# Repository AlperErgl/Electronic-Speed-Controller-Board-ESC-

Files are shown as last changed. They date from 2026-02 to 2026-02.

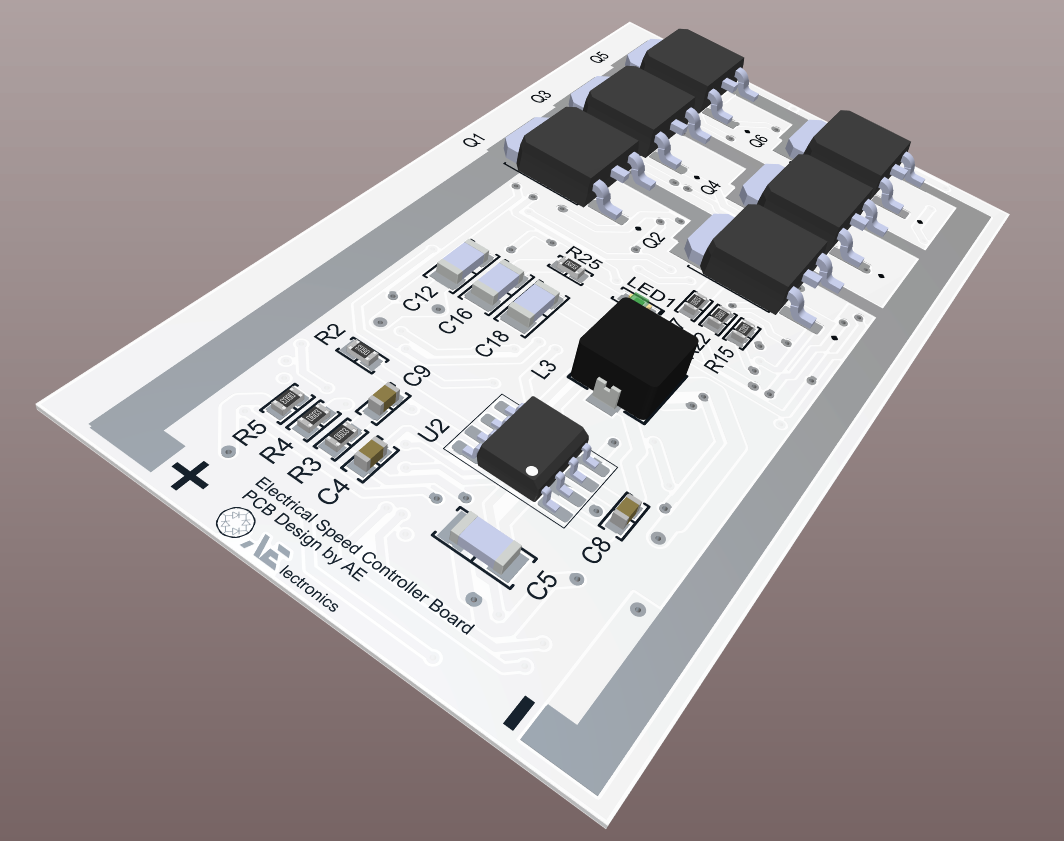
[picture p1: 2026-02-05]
ESC_Hardware/Documentation/Images/ESC Perspective View.png

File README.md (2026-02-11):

# Electronic-Speed-Controller-Board-ESC
Electronic Speed Controller (ESC) using PWM control, developed in C for embedded applications.

ESC Perspective View-Photoroom
 <p align="center">
 <i>Figure 1. Electronic Speed Controller Perspective View.</i>
</p>

## Project Overview

This project focuses on the design and implementation of a sensorless Brushless DC (BLDC) Electronic Speed Controller (ESC) developed as part of a graduation thesis. The system integrates both hardware and firmware, aiming to achieve reliable motor control using low-cost components and an open-source development approach.

The ESC is built around an ATmega328P microcontroller and operates using Back-EMF zero-crossing detection to determine rotor position without the use of Hall sensors. This sensorless approach reduces system complexity, cost, and mechanical dependency while maintaining efficient motor commutation.

The firmware is written in C/Arduino-based embedded C, directly configuring microcontroller registers for precise timing, PWM generation, and interrupt handling. The ESC accepts a standard RC PWM input signal (1000–2000 µs) and dynamically maps it to motor speed by adjusting PWM duty cycles.

On the hardware side, a custom PCB was designed, including MOSFET driver stages, power regulation, signal conditioning, and protection considerations. The project also includes EEPROM-based parameter storage, allowing the ESC to automatically learn and store throttle range values during configuration.

This project demonstrates practical experience in:

- Embedded systems programming

- Power electronics

- Motor control theory

- PCB design and hardware–software co-design

## Features

- Sensorless BLDC Motor Control
Uses Back-EMF zero-crossing detection for rotor position estimation without Hall sensors.

- Custom ESC Firmware
Firmware developed in embedded C with direct register-level control for timers, PWM, and interrupts.

- Standard RC PWM Input Support
Compatible with 1000–2000 µs PWM signals from RC receivers or flight controllers.

- Automatic Throttle Range Calibration
Throttle minimum and maximum values are detected on startup and stored in EEPROM.

- EEPROM-Based Parameter Storage
Persistent storage of configuration parameters across power cycles.

- Multi-Step Commutation Sequence
Six-step trapezoidal commutation with comparator-based zero-cross detection.

- Audible Status Feedback
Startup, configuration, and error states indicated via buzzer tones at different frequencies.

- Custom PCB Design
Includes schematic design, PCB layout, Gerber files, and Bill of Materials (BOM).

- Low-Cost and Open-Source Approach
Designed using widely available components and open development tools.

## Hardware Design

The hardware design of this Electronic Speed Controller (ESC) is based on a modular and clearly structured three-phase inverter topology, optimized for sensorless BLDC motor control. The system is powered by a Li-Po battery, which serves as the main DC energy source and is capable of supplying the high current required by the motor. To support the low-voltage control electronics, the battery voltage is stepped down using a high-efficiency switching regulator (MP2307DN-LF-Z), providing a stable 5 V supply rail for the microcontroller and auxiliary circuitry. The use of a switching regulator instead of a linear solution significantly improves efficiency and reduces thermal losses, which is critical for battery-powered systems.

<br>
<p align="center">
Başlıksız DiyagramDD drawio
</p>
<p align="center">
  <i>Figure 2. Overall hardware topology of the Electronic Speed Controller.</i>
</p>

<br>

At the core of the control system lies the ATmega328P microcontroller in a 32-pin LQFP package. The microcontroller is responsible for PWM signal generation, RC input signal processing, commutation timing, and Back-EMF zero-crossing detection. One of the key reasons for selecting the ATmega328P is its built-in analog comparator, which enables sensorless motor control without the need for external Hall sensors. This allows rotor position estimation by monitoring the floating motor phase voltage during each commutation step.

The motor drive stage consists of six IRLR7843 N-channel power MOSFETs arranged in a three-phase half-bridge configuration. These MOSFETs were selected due to their low RDS(on), logic-level gate drive compatibility, and high current handling capability, making them suitable for low-voltage, high-current BLDC applications. Each motor phase is driven by a complementary high-side and low-side MOSFET pair, allowing precise control of current flow through the motor windings.

Gate control for the MOSFETs is provided by three IR2101 high-side / low-side gate driver ICs, with each driver dedicated to one motor phase. The IR2101 enables reliable high-side N-channel MOSFET driving through internal level shifting and bootstrap circuitry. This architecture ensures fast switching transitions, proper gate voltage levels, and safe operation by minimizing the risk of shoot-through conditions.

The three motor phases are structured as AH/AL for Phase A, BH/BL for Phase B, and CH/CL for Phase C, where the high-side (H) MOSFET connects the phase to the positive supply rail and the low-side (L) MOSFET connects it to ground. During operation, the ESC follows a six-step trapezoidal commutation sequence. At any given time, one phase is actively driven high, one phase is driven low, and the remaining phase is left electrically floating. The floating phase voltage is used for Back-EMF sensing, allowing the microcontroller to detect zero-crossing events and determine the optimal timing for the next commutation step.

<br>
<p align="center">
ESC-Circuit
</p>
<p align="center">
  <i>Figure 3. ESC Circuit Diagram.</i>
</p>

The complete electrical implementation of this architecture can be seen in the provided schematic diagram, which illustrates the power stage, gate driver connections, microcontroller interfacing, and Back-EMF sensing paths. The schematic highlights the separation between high-power and low-power domains, ensuring both electrical safety and signal integrity. Special attention has been given to grounding, decoupling, and signal routing to improve noise immunity and overall system reliability.

<br>
<p align="center">
ESC Bottom 2D
</p>
<p align="center">
  <i>Figure 4. ESC Bottom 2D View.</i>
</p>

Overall, the hardware design achieves a balance between performance, simplicity, and educational clarity. It demonstrates a fully functional sensorless BLDC ESC architecture using widely available components, making it suitable for academic projects, prototyping, and further development.

<br>
<p align="center">
ESC Bottom View
</p>
<p align="center">
  <i>Figure 5. ESC 3D View.</i>
</p>

## Firmware / Software Design

The ESC firmware is implemented in C/C++ using the Arduino framework and is specifically designed for real-time, sensorless BLDC motor control. The software architecture follows a modular design approach, where motor control logic, hardware abstraction, persistent configuration storage, and user feedback mechanisms are separated into dedicated source and header files. This structure improves maintainability, enhances code readability, and allows individual subsystems to be modified or extended independently without affecting the overall system behavior.

### PWM Input Measurement and Processing

The main firmware file (ESC_V3_Code.ino) handles system initialization, PWM input measurement, motor state control, and commutation sequencing. During startup, all GPIOs, timers, and internal peripherals are configured. The incoming PWM signal from the RC receiver is measured and mapped to a valid motor speed range while enforcing predefined safety limits.

```c
if (PWM_INPUT > PWM_IN_MAX) PWM_INPUT = PWM_IN_MAX;
if (PWM_INPUT < PWM_IN_MIN) PWM_INPUT = PWM_IN_MIN;

```
This ensures that invalid or noisy input signals cannot command unsafe motor behavior.
<br>
<br>
### Sensorless Commutation and Back-EMF Detection

Motor commutation is implemented using a six-step trapezoidal algorithm. At each step, two phases are actively driven while the third phase is left floating. The floating phase voltage is monitored using the ATmega328P’s internal analog comparator to detect Back-EMF zero-crossing events, which are used to determine the correct timing for the next commutation step.

This method enables fully sensorless operation without external position sensors, reducing system complexity and hardware cost.
<br>
<br>
### PWM Generation and Motor Speed Control

Motor speed is controlled by adjusting the PWM duty cycle applied to the active MOSFETs. Hardware timers are used to generate stable PWM signals, allowing precise control over the effective motor voltage.

```c
#define PWM_max_value 255
#define PWM_min_value 35
```
These limits prevent operation in regions where torque is insufficient or switching losses become excessive.
<br>
<br>
### Non-Volatile Configuration Storage (EEPROM)

Calibration parameters such as minimum and maximum PWM input values are stored in EEPROM to persist across power cycles. A generic EEPROM abstraction layer allows arbitrary data types to be stored and retrieved safely.

```c
EEPROM_writeAnything(PWM_IN_MIN_ADRESS, PWM_IN_MIN);
EEPROM_readAnything(PWM_IN_MAX_ADRESS, PWM_IN_MAX);
```
This feature eliminates the need for repeated calibration and improves user experience.
<br>
<br>
### Audible Feedback System

An audible feedback system is implemented using a buzzer to indicate system states such as startup, calibration, and operational modes. Different tones are generated by toggling GPIO pins with precise timing delays.

```c
void beep_1KHZ(int milliseconds);
void beep_2KHZ(int milliseconds);
void beep_3KHZ(int milliseconds);
```
Audible feedback provides a simple yet effective human–machine interface without requiring additional displays or communication protocols.
<br>
<br>
### Global Configuration and State Management

System-wide parameters, operational flags, and timing variables are centralized in a dedicated header file. These variables track motor state, PWM thresholds, timing counters, and safety conditions such as motor stop detection.

```c
bool MOTOR_SPINNING = false;
bool ESC_MODE_ON = false;
bool PWM_RANGE_SET = false;
```
Centralizing these definitions ensures consistent behavior across the firmware and simplifies debugging.
<br>
<br>
### Software Design Summary

The firmware is designed to complement the hardware architecture by leveraging the microcontroller’s internal peripherals to their full potential. By combining modular code organization, sensorless control algorithms, and persistent configuration storage, the software achieves reliable real-time motor control while remaining compact, readable, and suitable for academic and professional embedded systems development.

### Firmware Upload and Programming Methodology

During the software development process, a USBasp programmer and an FTDI (USB-to-UART) interface are utilized to program the ATmega328P microcontroller. The microcontroller used in the ESC design is provided as a raw device without any factory-installed bootloader, which means that direct hardware-level access is required for initial programming.

<br>
<p align="center">
sss
</p>
<p align="center">
  <i>Figure 6. Overall firmware topology of the Electronic Speed Controller.</i>
</p>

In the first stage, the bootloader is written to the microcontroller using the In-System Programming (ISP) method. This low-level programming approach provides direct access to the microcontroller through the SPI lines (MOSI, MISO, SCK, and RESET). A widely supported programmer, USBasp, is employed to establish direct communication between the computer and the microcontroller, enabling reliable bootloader installation.

Once the bootloader has been successfully uploaded via the ISP interface, the system becomes ready for higher-level programming. At this stage, an FTDI module is connected to enable USB-to-serial (UART) communication, allowing firmware to be uploaded through the serial port. This programming sequence is a common and necessary practice when working with microcontrollers that do not include a pre-installed bootloader and represents a critical step in ensuring proper software–hardware integration.

Following bootloader installation, firmware development and code uploads can be performed using development tools such as Arduino IDE, Atmel Studio, or AVRDude. The use of the FTDI interface significantly simplifies the programming workflow, enabling rapid firmware updates, debugging, and functional testing without requiring repeated low-level programming. This approach accelerates the development cycle and supports a flexible, maintainable, and easily updatable software architecture for the ESC system.

## Repository Structure

The repository is organized in a modular and hierarchical manner to clearly separate
firmware and hardware-related files. This structure improves readability, simplifies
navigation, and allows independent development and maintenance of software and hardware
components.

```Repository Structure

ESC_V3_Code/
├── ESC_V3_Code.ino          # Main firmware source file
├── Beeps.h                  # Audible feedback routines
├── EEPROMAnything.h         # EEPROM read/write utilities
├── Variables.h              # Global definitions and system parameters

ESC_V3_Hardware/
├── PCB_Documents/
│ ├── ESC_Schematic.pdf        # Exported circuit schematic (PDF)
│ ├── ESCV3.PcbDoc             # PCB layout file
│ ├── ESCV3.PcbLib             # PCB footprint library
│ ├── ESCV3.PrjPcb             # Altium project file
│ ├── ESCV3.PrjPcbStructure    # Project structure and hierarchy
│ ├── ESCV3.SchDoc             # Schematic design file
│ └── ESCV3.SchLib             # Schematic symbol library
│
├── Gerber_Files/
│   ├── TopCopper.gbr
│   ├── BottomCopper.gbr
│   ├── SolderMask_Top.gbr
│   ├── SolderMask_Bottom.gbr
│   ├── Silkscreen_Top.gbr
│   └── DrillFiles.drl
│
├── Documentation/
│   ├── BOM.xlsx             # Bill of Materials
│   ├── Schematic.pdf        # Exported circuit schematic
│   └── Hardware_Photos/     # Assembly and board images

```

## Getting Started

This section describes the complete process required to assemble, program, and prepare the ESC for operation, starting from hardware assembly to firmware upload and final calibration.

The assembly process begins with soldering all electronic components onto the PCB according to the schematic. Special attention is given to the power input terminals (+ and −), where a thick solder layer is applied to improve current handling capability and enhance thermal dissipation. After reinforcing these pads, power supply cables are soldered to the corresponding terminals to allow stable connection to the main power source.

<br>
<p align="center">

</p>
<p align="center">
  <i>Figure 7. Soldering and assembly processes.</i>
</p>

Next, the motor phase connections are prepared. Three high-current output pads connected to the power MOSFET stages are used for the motor phases. Three cables are soldered to these pads, forming the Phase A, Phase B, and Phase C outputs required to drive the BLDC motor.

Following the power stage assembly, the PWM signal wiring is completed. The signal cable from the RC receiver is connected to the designated PWM input pin, along with the required ground reference, enabling throttle control via an external controller.

Once the hardware setup is completed, the software preparation stage begins. Since the ATmega328P microcontroller does not include a factory-installed bootloader, an initial bootloader upload is required. This is performed using a USBasp programmer via the ISP interface. After the bootloader is installed, firmware can be uploaded through the serial interface using an FTDI module. Detailed firmware architecture and programming steps are described in the Firmware section.

After firmware upload, the ESC is ready for operation. The motor phases and power supply are connected, and the system is powered on. Throttle calibration is then performed using a standard RC transmitter, following the same procedure commonly used in commercial ESCs: the throttle stick is first set to the maximum position during power-up, followed by an audible confirmation beep, then moved to the minimum position where a second beep confirms successful calibration. After this process, the ESC is fully calibrated and ready for use in real-world applications.

## Limitations and Future Work

The results obtained in this study demonstrate that a basic Electronic Speed Controller (ESC) can be designed and implemented in a functional and cost-effective manner. However, the current system does not include several advanced ESC features commonly found in commercial or high-performance applications. The following improvements are proposed for future work:

- Closed-Loop Control: The system currently operates in open-loop mode. By integrating Hall sensors or utilizing back-EMF (BEMF) feedback, closed-loop speed control can be implemented, allowing direct motor speed measurement and improved control accuracy.

- Thermal and Current Protection: The present design does not monitor temperature or phase current. Integrating thermal sensors for MOSFET temperature monitoring and current sensors for phase current measurement would significantly enhance system safety and reliability.

- Field-Oriented Control (FOC): The existing control algorithm is based on trapezoidal commutation. Implementing a Field-Oriented Control (FOC) algorithm could improve efficiency, torque smoothness, and overall motor performance.

- High-Frequency PWM Operation: Increasing the PWM switching frequency beyond the audible range could reduce acoustic noise during ESC operation.

- Wireless Communication and Calibration: A UART-based or Bluetooth communication interface could be added to enable wireless parameter tuning, calibration, and real-time monitoring.

- Multi-ESC Synchronization: For applications requiring multiple ESCs operating simultaneously, such as multirotor platforms, synchronization mechanisms could be developed to ensure coordinated operation.

By implementing these enhancements, the system’s safety, control precision, and applicability would be significantly improved, enabling its use in advanced applications such as autonomous aerial vehicles.

## Conclusion

In this study, a functional and cost-effective Electronic Speed Controller (ESC) was successfully designed and implemented by integrating power electronics, embedded firmware, and real-time control principles. The project demonstrates that a reliable sensorless BLDC motor control system can be achieved using a minimal hardware platform and a modular software architecture. Throughout the development process, emphasis was placed on hardware–software integration, safety-oriented design, and practical usability. The resulting ESC provides a solid foundation for further enhancements and serves as a strong demonstration of embedded systems and power electronics engineering skills.

## License

This project is licensed under the MIT License.
You are free to use, modify, and distribute this project for personal or commercial purposes, provided that the original license and copyright notice are included.

## Author

Alperen Ergül
Electrical and Electronics Engineer

Email: alp-ergl@hotmail.com

GitHub: https://github.com/AlperErgl

LinkedIn: www.linkedin.com/in/alperen-ergül

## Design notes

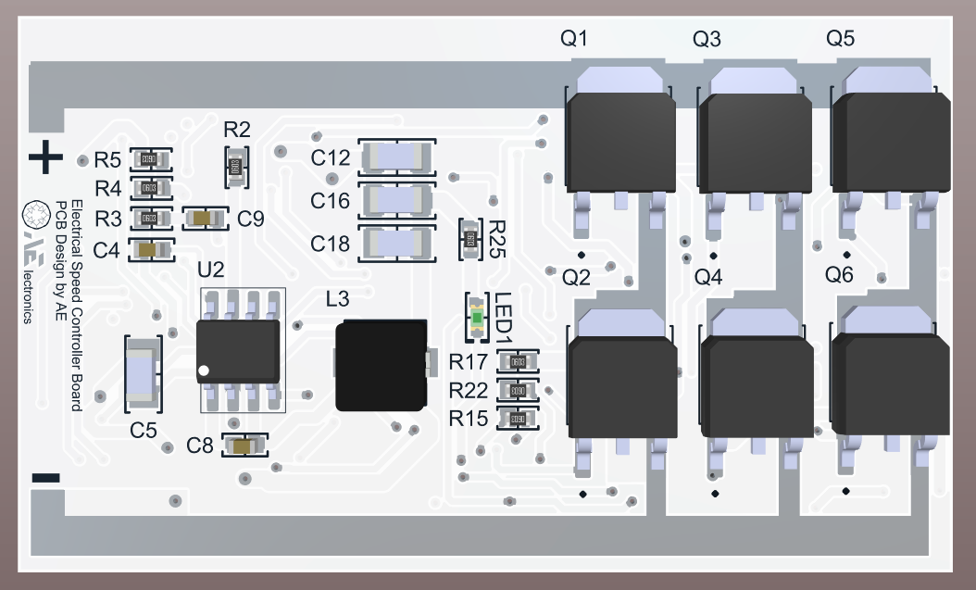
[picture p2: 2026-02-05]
ESC_Hardware/Documentation/Images/ESC Top View.png

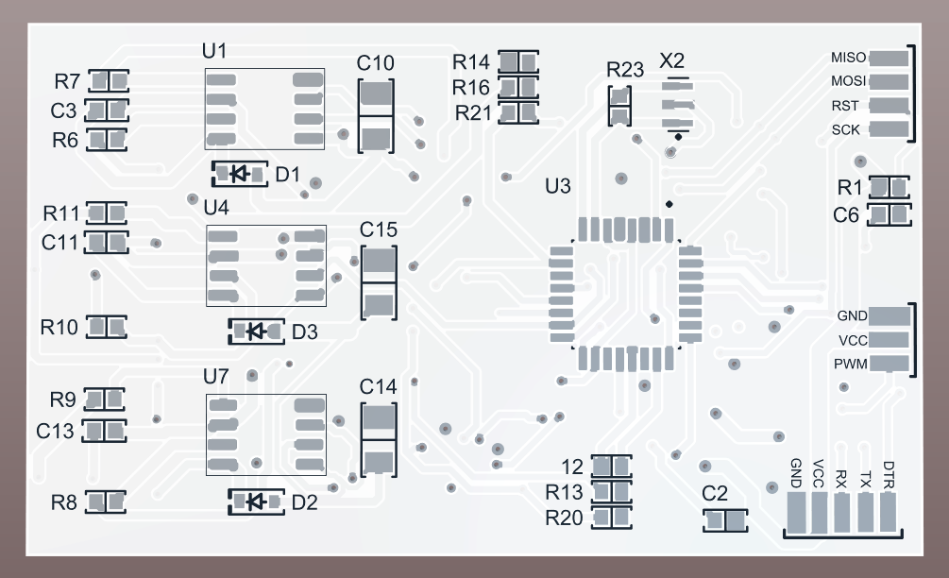
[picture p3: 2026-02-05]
ESC_Hardware/Documentation/Images/ESC Bottom 3D Bodies off.png

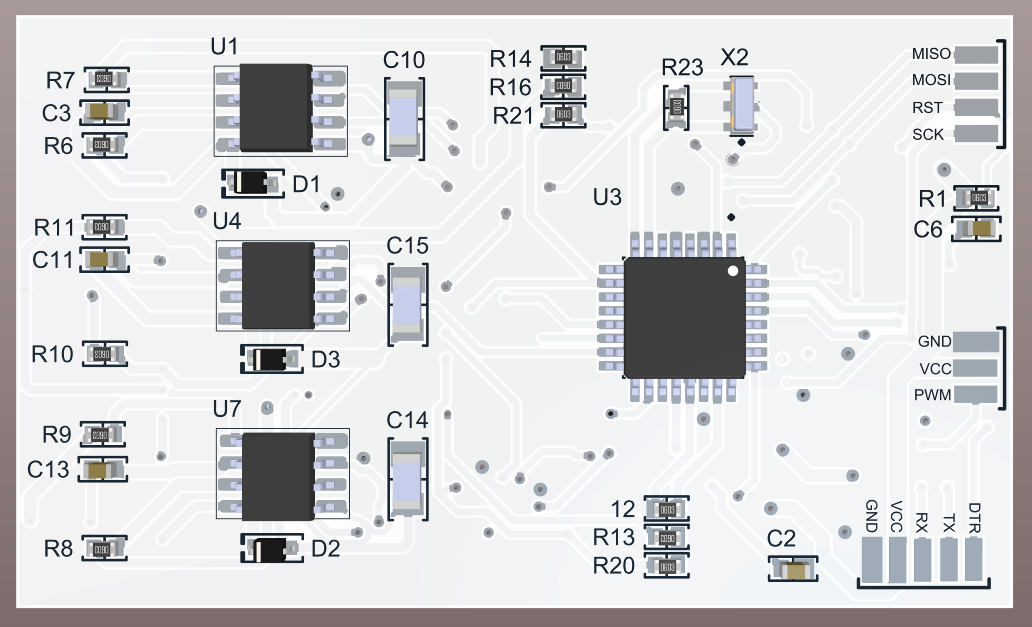
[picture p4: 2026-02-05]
ESC_Hardware/Documentation/Images/ESC Bottom View.png

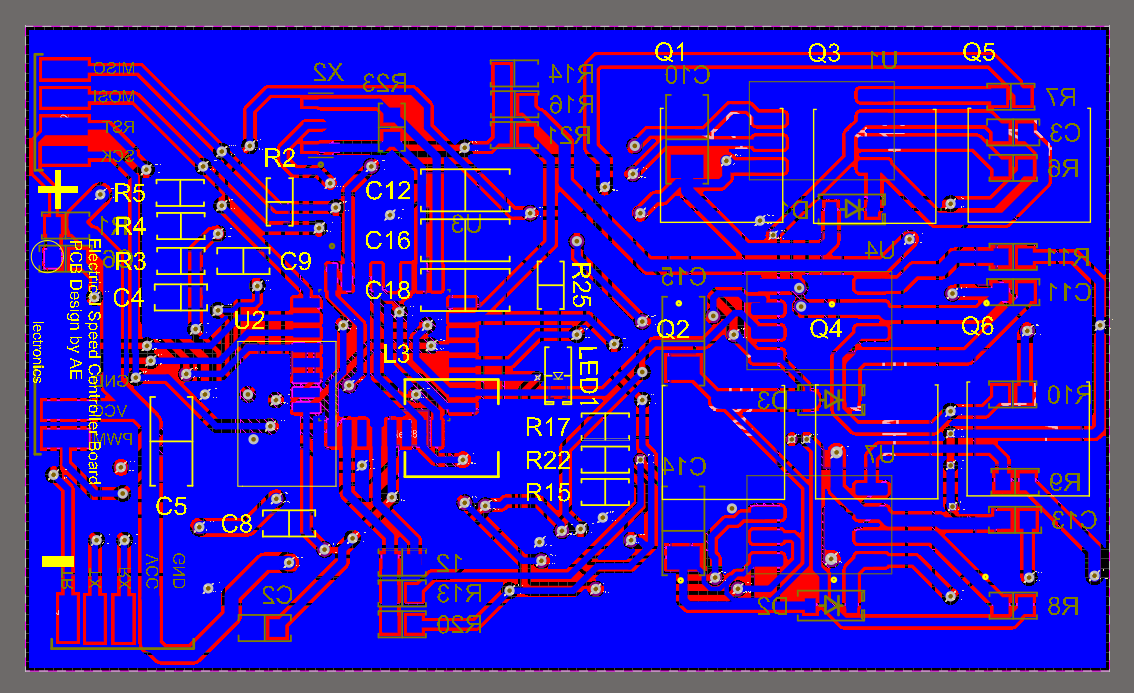
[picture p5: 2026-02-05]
ESC_Hardware/Documentation/Images/ESC Bottom 2D.png

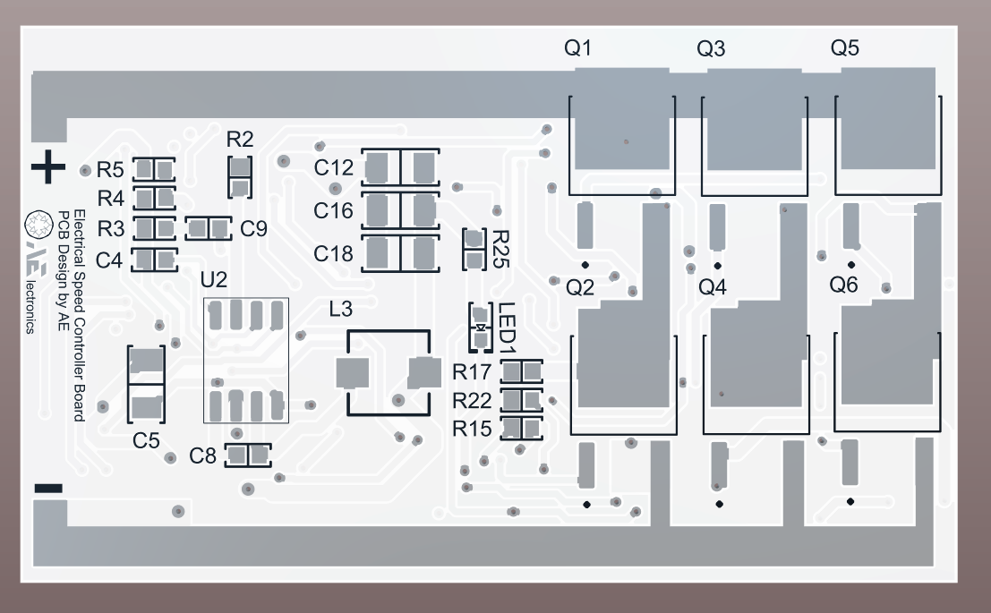
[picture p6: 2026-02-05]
ESC_Hardware/Documentation/Images/ESC Top 3D Bodies off.png

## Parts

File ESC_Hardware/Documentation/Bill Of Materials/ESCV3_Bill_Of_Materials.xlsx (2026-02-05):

Comment | Description | Designator | Footprint | LibRef | Quantity
10 kOhms | RES 10K OHM 0.1% 1/16W 0603 | 12, R1, R4, R14, R15, R23 | RES 0603_1608 | RNCS0603BKE10K0 | 6
100 nF | CAP CER 3.9PF 250V C0G/NP0 0603 | C2, C4, C6 | CAP 0603_1608 | CBR06C399BAGAC | 3
2.2 uF | CAP CER 3.9PF 250V C0G/NP0 0603 | C3, C11, C13 | CAP 0603_1608 | CBR06C399BAGAC | 3
10 µF | CAP CER 10UF 16V X5R 1206 | C5, C10, C14, C15 | CAP 1206_3216 - 0.8MM | EMK316BJ106MD-T | 4
_x0008__x0008_10 nF | CAP CER 3.9PF 250V C0G/NP0 0603 | C8 | CAP 0603_1608 | CBR06C399BAGAC | 1
3.9 nF | CAP CER 3.9PF 250V C0G/NP0 0603 | C9 | CAP 0603_1608 | CBR06C399BAGAC | 1
22 µF | CAP CER 22UF 16V X5R 1206 | C12, C16, C18 | CAP 1206_3216 - 0.8MM | CL31A226MOCLNNC | 3
1N4148WS-7-F | DIODE GEN PURP 75V 150MA SOD323 | D1, D2, D3 | SOD323 | 1N4148WS-7-F | 3
10 µH | FIXED IND 10UH 2.75A 128MOHM SMD | L3 | BOURNS SRP5030T | SRP5030T-100M | 1
Green | LED GREEN CLEAR CHIP 0603 SMD | LED1 | LED 0603_1608 GREEN | LSM0603453V | 1
IRLR7843TRPBF | RoHS Compliant | Industry-leading quality | Low RDS(ON) at 4.5V VGS | Fully Characterized Avalanche Voltage and Current | Ultra-Low Gate Impedance | Logic Level | Q1, Q2, Q3, Q4, Q5, Q6 | TO229P990X239-3_4N | IRLR7843TRPBF | 6
100 kOhms | RES 100K OHM 0.1% 1/16W 0603 | R2 | RES 0603_1608 | RNCS0603BKE100K | 1
6.81 kOhms | RQ 0603 6K81 0.1% 10PPM 1K RL | R3 | RES 0603_1608 | RQ73C1J6K81BTDF | 1
44.2 kOhms | RES SMD 44.2K OHM 0.1% 1/5W 0603 | R5 | RES 0603_1608 | ERJ-PB3B4422V | 1
100 Ohms | RES 100 OHM 0.1% 1/16W 0603 | R6, R7, R8, R9, R10, R11, R25 | RES 0603_1608 | RNCS0603BKE100R | 7
33 kOhms | RES SMD 33K OHM 0.1% 1/16W 0603 | R13, R16, R17, R20, R21, R22 | RES 0603_1608 | CPF0603B33KE1 | 6
IR2101STRPBF |  | U1, U4, U7 | IR2101STRPBF | IR2101STRPBF | 3
MP2307DN-LF-Z |  | U2 | MP2307DN-LF-Z | MP2307DN-LF-Z | 1
ATMEGA328P-AU | AVR AVRÂ® ATmega Microcontroller IC 8-Bit 20MHz 32KB (16K x 16) FLASH 32-TQFP (7x7) | U3 | QFP80P900X900X120-32N | ATMEGA328P-AU | 1
CSTCE16M0V53Z-R0 | 20MHz Ceramic Resonator Built in Capacitor 15pF +/- 0.2% -40C - 125C Surface Mount | X2 | OSC_CSTCE16M0V53Z-R0 | CSTCE16M0V53Z-R0 | 1

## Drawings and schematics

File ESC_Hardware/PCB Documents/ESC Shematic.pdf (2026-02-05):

# POWER BLOCK 3-PHASE BRIDGE

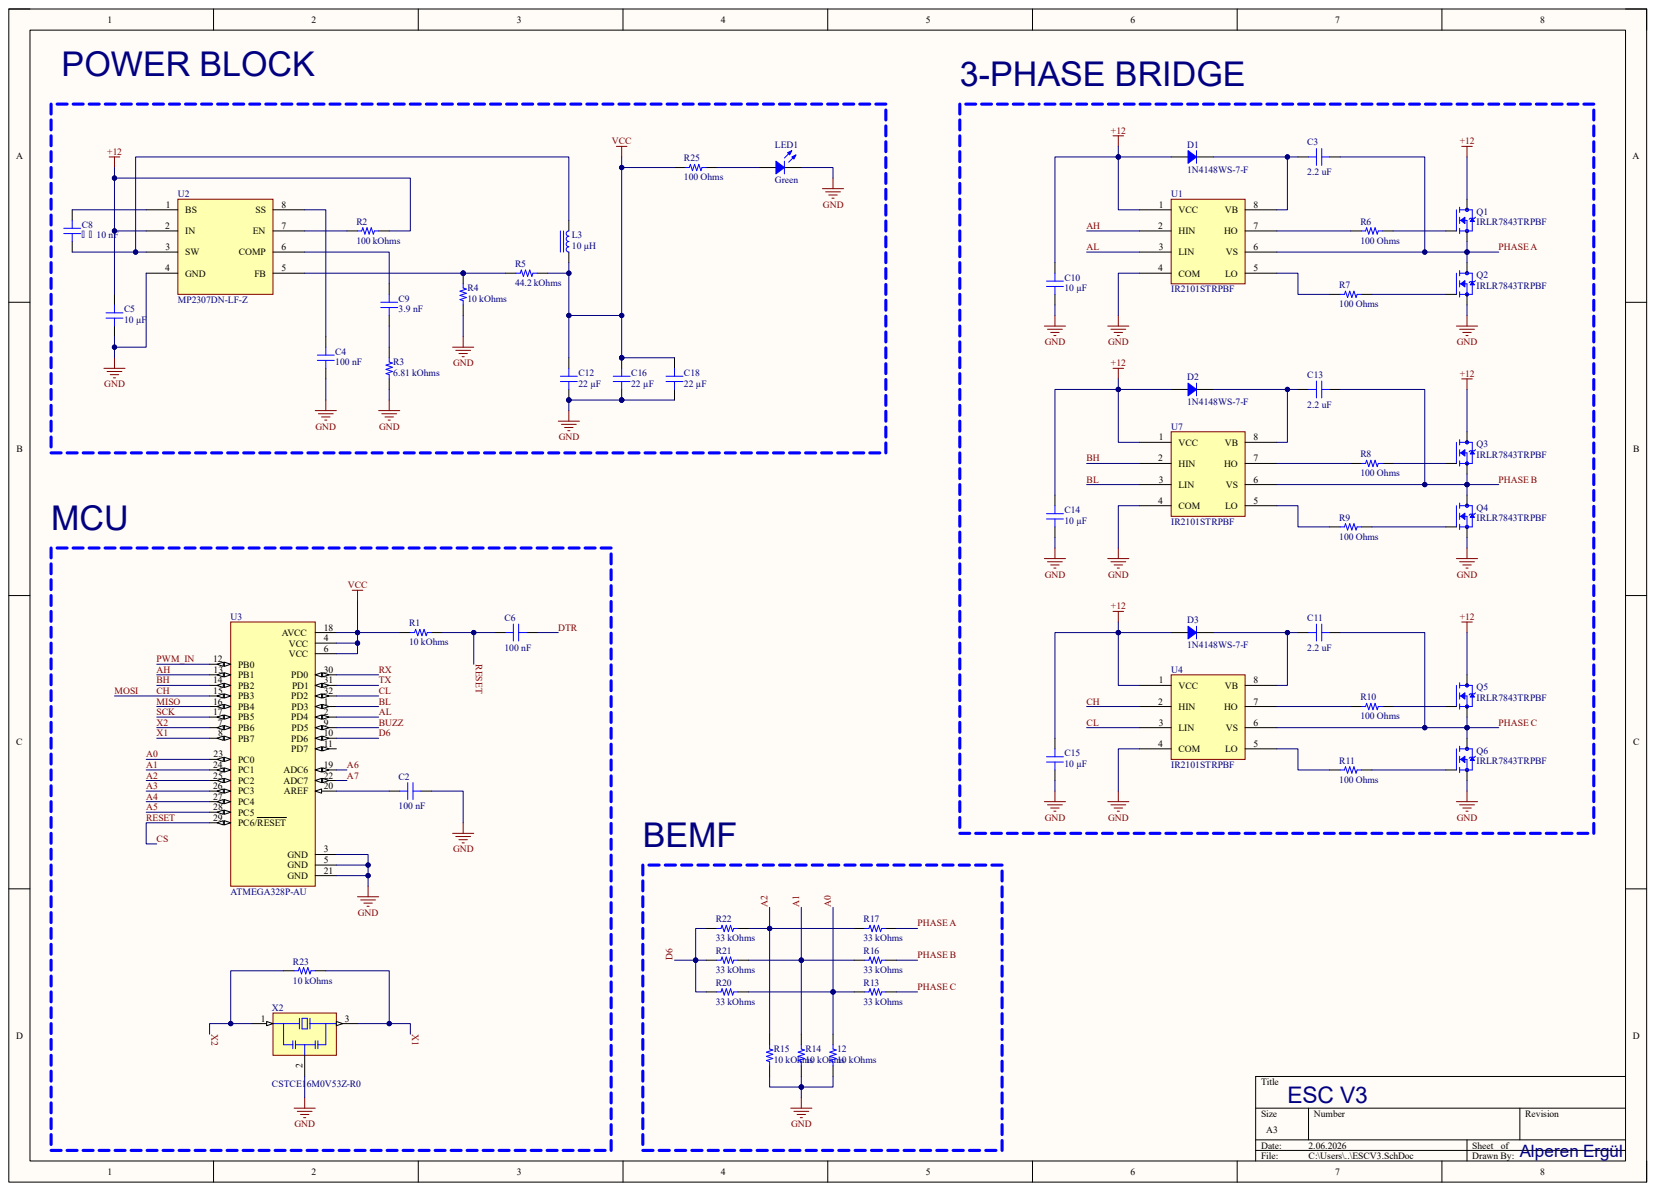
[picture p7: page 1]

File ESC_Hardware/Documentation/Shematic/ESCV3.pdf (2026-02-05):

# POWER BLOCK 3-PHASE BRIDGE

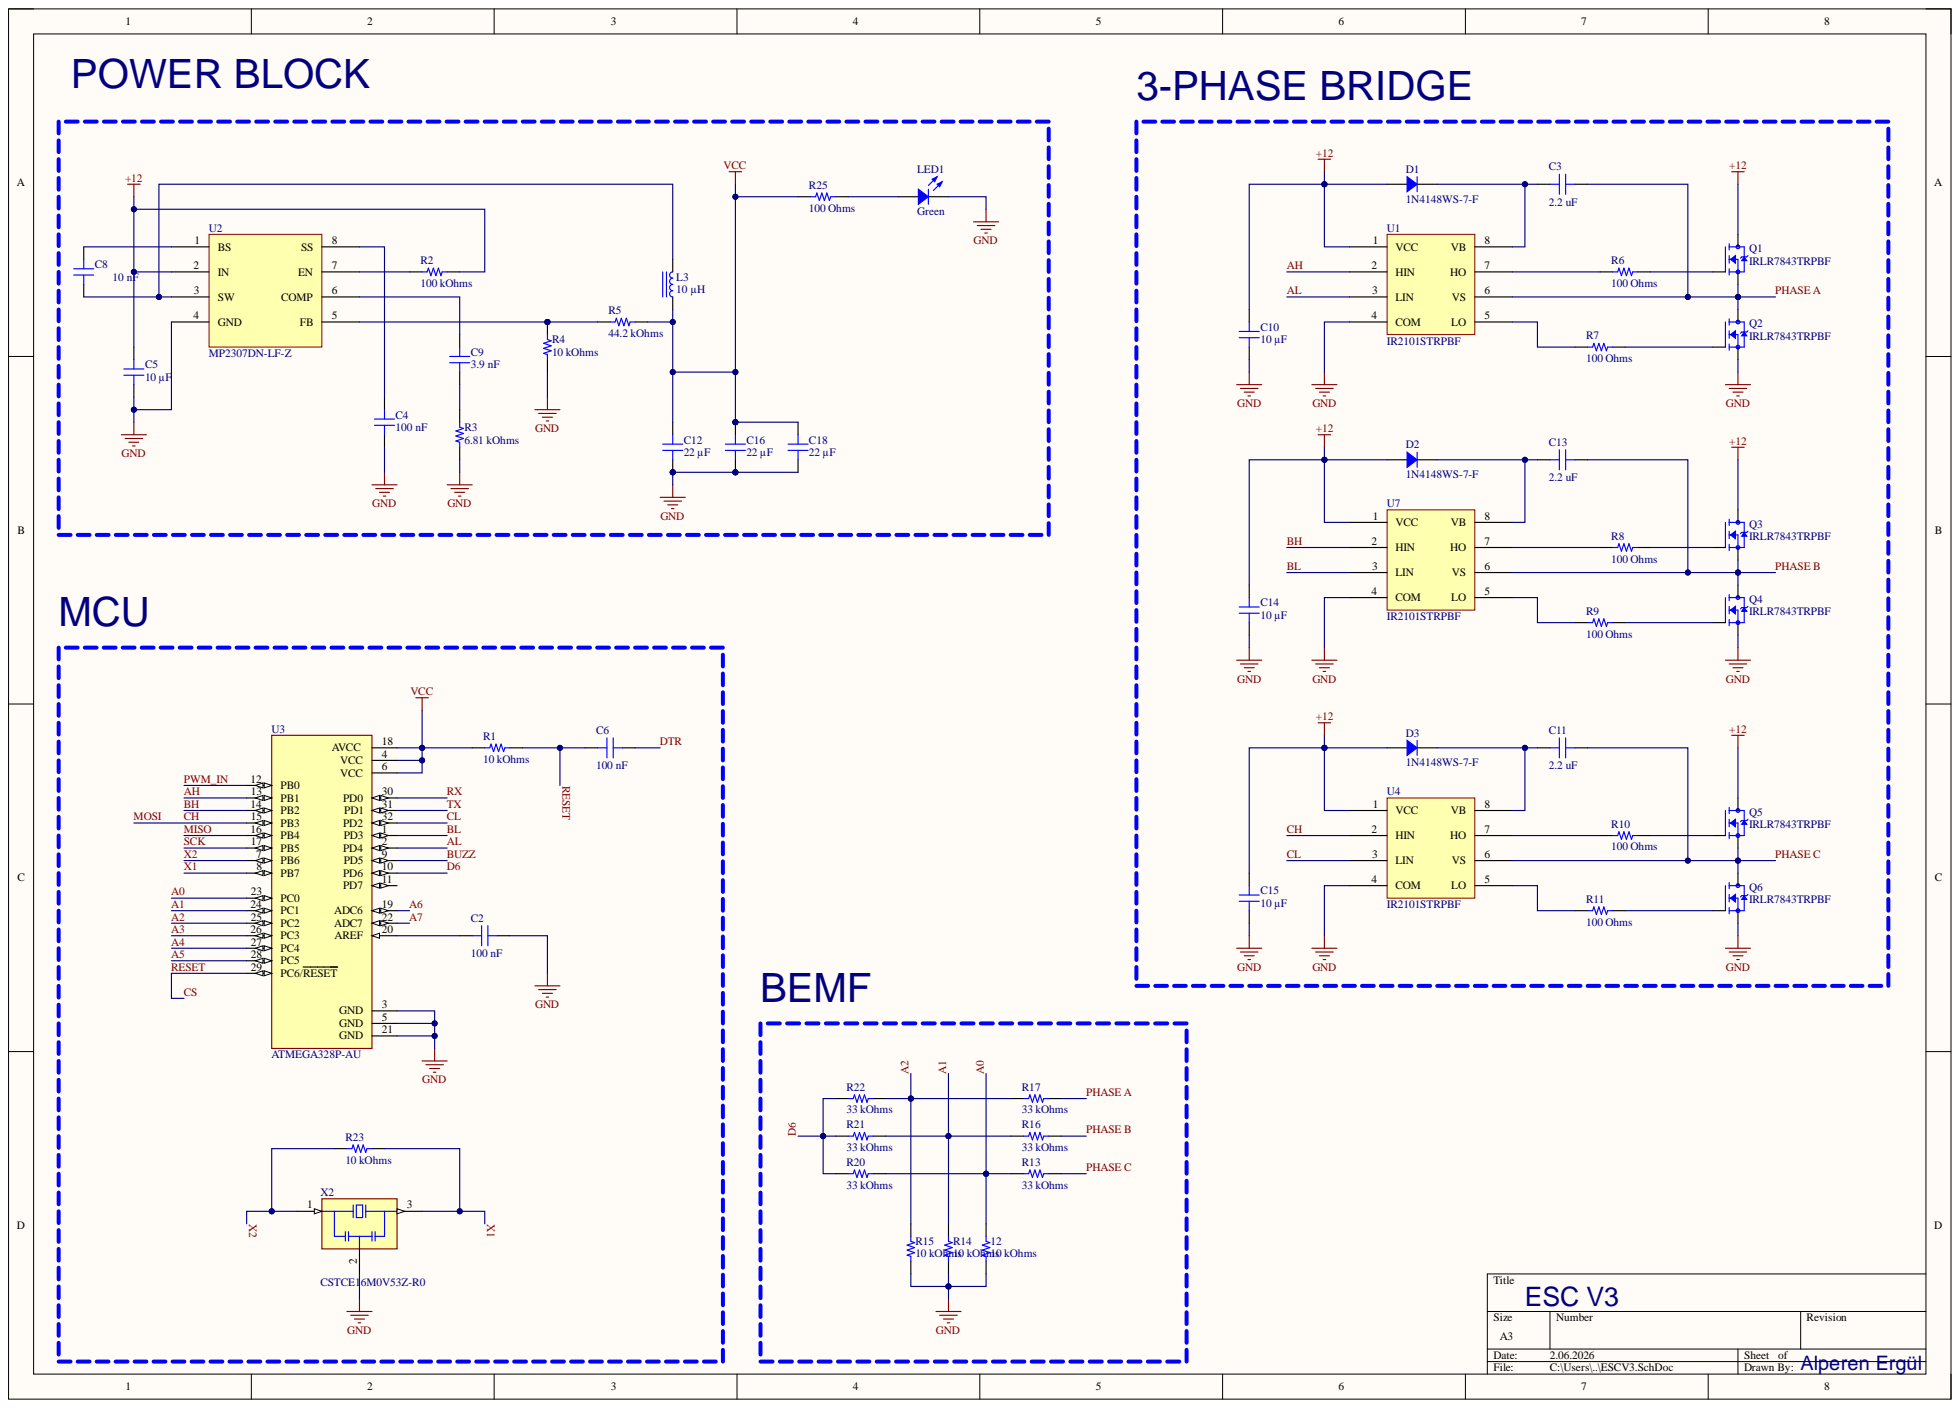
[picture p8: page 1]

Comment | Description | Designator | Footprint | LibRef | Quantity
10kOhms | RES10KOHM0.1% 1/16W0603 | 12, R1, R4, R14, R15, R23 | RES0603_1608 | RNCS0603BKE10K0 | 6
100nF | CAPCER3.9PF250V C0G/NP00603 | C2, C4, C6 | CAP0603_1608 | CBR06C399BAGAC | 3
2.2uF | CAPCER3.9PF250V C0G/NP00603 | C3, C11, C13 | CAP0603_1608 | CBR06C399BAGAC | 3
10µF | CAPCER10UF16V X5R1206 | C5, C10, C14, C15 | CAP1206_3216-0.8MM | EMK316BJ106MD-T | 4
10nF | CAPCER3.9PF250V C0G/NP00603 | C8 | CAP0603_1608 | CBR06C399BAGAC | 1
3.9nF | CAPCER3.9PF250V C0G/NP00603 | C9 | CAP0603_1608 | CBR06C399BAGAC | 1
22µF | CAPCER22UF16V X5R1206 | C12, C16, C18 | CAP1206_3216-0.8MM | CL31A226MOCLNNC | 3
1N4148WS-7-F | DIODEGEN PURP75V 150MASOD323 | D1, D2, D3 | SOD323 | 1N4148WS-7-F | 3
10µH | FIXEDIND10UH2.75A 128MOHMSMD | L3 | BOURNSSRP5030T | SRP5030T-100M | 1
Green | LEDGREEN CLEAR CHIP0603SMD | LED1 | LED0603_1608GREEN | LSM0603453V | 1
IRLR7843TRPBF | RoHSCompliant | Industry-leading quality| Low RDS(ON) at 4.5VVGS | FullyCharacterized AvalancheVoltage and Current | Ultra-LowGateImpedance | Logic Level | Q1, Q2, Q3, Q4, Q5, Q6 | TO229P990X239-3_4N | IRLR7843TRPBF | 6
100kOhms | RES100KOHM0.1% 1/16W0603 | R2 | RES0603_1608 | RNCS0603BKE100K | 1
6.81kOhms | RQ06036K810.1% 10PPM1KRL | R3 | RES0603_1608 | RQ73C1J6K81BTDF | 1
44.2kOhms | RESSMD44.2KOHM 0.1%1/5W0603 | R5 | RES0603_1608 | ERJ-PB3B4422V | 1
100Ohms | RES100OHM0.1% 1/16W0603 | R6, R7, R8, R9, R10, R11, R25 | RES0603_1608 | RNCS0603BKE100R | 7
33kOhms | RESSMD33KOHM 0.1%1/16W0603 | R13, R16, R17, R20, R21, R22 | RES0603_1608 | CPF0603B33KE1 | 6
IR2101STRPBF | | U1, U4, U7 | IR2101STRPBF | IR2101STRPBF | 3
MP2307DN-LF-Z | | U2 | MP2307DN-LF-Z | MP2307DN-LF-Z | 1
ATMEGA328P-AU | AVRAVRÂ®ATmega Microcontroller IC8-Bit 20MHz32KB(16Kx 16) FLASH32-TQFP (7x7) | U3 | QFP80P900X900X120-32N | ATMEGA328P-AU | 1
CSTCE16M0V53Z-R0 | 20MHzCeramic Resonator Built in Capacitor 15pF+/-0.2%-40C- 125C SurfaceMount | X2 | OSC_CSTCE16M0V53Z-R0 | CSTCE16M0V53Z-R0 | 1

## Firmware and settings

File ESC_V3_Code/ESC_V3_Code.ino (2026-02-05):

#include "EEPROMAnything.h"         //This is used to store more than just one byte to the EEPROM
#include "Beeps.h"  
#include "Variables.h"  


void setup() {  
  
  if( EEPROM.read(1) != 1)      //This will only run once after you uplaod the code
  {
    EEPROM_writeAnything(PWM_IN_MIN_ADRESS, PWM_IN_MIN);         
    EEPROM_writeAnything(PWM_IN_MAX_ADRESS, PWM_IN_MAX);  
    EEPROM.write(1, 1);
  }     
  
  /*#error First time you uplaod the code make sure the next line is "uncommented". 
  Then, comment back the line and uplaod the code again and delete this entire error line*/
  //EEPROM.write(1, 0);
  
  //Our pins for the MNSFET drivers are 2,3,4 and 9,10,11
  DDRD  |= B00011100;           //Configure pins 2, 3 and 4 as outputs CL, BL and AL
  PORTD  = B00000000;           //Pins 0 to 7 set to LOW
  DDRB  |= B00001110;           //Configure pins 9, 10 and 11 as outputs
  PORTB  &= B00110001;          //D9, D10 and D11 to LOW
  // Timer1
  TCCR1A = 0;
  TCCR1B = 0x01;
  // Timer2
  TCCR2A = 0;
  TCCR2B = 0x01;
  // Comparator on pin D6
  ACSR   = 0x10;                // Clear flag comparator interrupt
  //Set D8 (PWM in) to trigger interrupt (we use this to read PWM input)
  PCICR |= (1 << PCIE0);        //enable PCMSK0 scan                                                 
  PCMSK0 |= (1 << PCINT0);      //Set pin D8 trigger an interrupt on state change. 

  /*Now we detect the PWM input and if is higher than  we enter 
  configuration mode and if not, we jump to the void loop*/
  delay(50);
  //Power on mode select
  if(PWM_INPUT > PWM_IN_MIN + 115)
  {
     ESC_MODE_ON = false;       //Motor rotation is OFF till the config mode is done
    while(!PWM_RANGE_SET)
    { 
      currentMillis = millis();
      if(currentMillis - previousMillis >= 500)
      {
        OCR1A = beeping_PWM_VALUE;
        previousMillis += 500;   
        TCCR2A =  0;            //OC2A - D11 normal port.    
        TCCR1A =  0;            // OC1A and OC1B normal port
        beep_1KHZ(100);         
      }
      if(PWM_INPUT > MAX_PWM_TO_STORE)
      {
        MAX_PWM_TO_STORE = PWM_INPUT;
      }
      
      if(PWM_INPUT < 1200)
      {
        if(pwm_set_counter > 1000)
        {
          MIN_PWM_TO_STORE = PWM_INPUT;
          EEPROM_writeAnything(PWM_IN_MIN_ADRESS, MIN_PWM_TO_STORE);         
          EEPROM_writeAnything(PWM_IN_MAX_ADRESS, MAX_PWM_TO_STORE); 
          ESC_MODE_ON = true;
          PWM_RANGE_SET = true;
          int y = 0;          
          TCCR2A =  0;            //OC2A - D11 normal port.    
          TCCR1A =  0;            // OC1A and OC1B normal port
          beep_1KHZ(400);
          delay(200);
           
          TCCR2A =  0;            //OC2A - D11 normal port.    
          TCCR1A =  0;            // OC1A and OC1B normal port
          
          beep_1KHZ(100);
          delay(100);
          beep_2KHZ(100);
          delay(100);
          beep_3KHZ(100);
          delay(100);
          
                   
        }
        pwm_set_counter = pwm_set_counter + 1;
        delay(1);
      }
      else
      {
        pwm_set_counter = 0;
      }     
    }//end of !PWM_RANGE_SET
  }

  /*If the range is below PWM_IN_MIN+115us then we start the code*/
  else
  {
    OCR1A = beeping_PWM_VALUE;
    ESC_MODE_ON = true;
    int x = 0;      
    TCCR2A =  0;            //OC2A - D11 normal port.    
    TCCR1A =  0;            // OC1A and OC1B normal port
    beep_1KHZ(400);
    delay(200);
    
    TCCR2A =  0;            //OC2A - D11 normal port.    
    TCCR1A =  0;            // OC1A and OC1B normal port
    
    beep_1KHZ(100);
    delay(100);
    beep_2KHZ(100);
    delay(100);
    beep_3KHZ(100);
    delay(100);
       
  }
  
//Save new range to the EEPROM  
EEPROM_readAnything(PWM_IN_MIN_ADRESS, PWM_IN_MIN);
EEPROM_readAnything(PWM_IN_MAX_ADRESS, PWM_IN_MAX);
}//End of setup loop






// Interrumption vector for the Analog comparator
ISR (ANALOG_COMP_vect) {
  for(i = 0; i < 10; i++) {           //We check the comparator 10 times just to be sure
    if(sequence_step & 1)             //If step = odd (0001, 0011, 0101) 1, 3 or 5
    {
      if(!(ACSR & B00100000)) i -= 1; //!B00100000 -> B11011111 ACO = 0 (Analog Comparator Output = 0)
    }
    else                              //else if step is 0, 2 or 4
    {
      if((ACSR & B00100000))  i -= 1; //else if B00100000 -> B11011111 ACO = 1 (Analog Comparator Output = 1)
    }
  }
  set_next_step();                    //set the next step of the sequence
  sequence_step++;                    //increment step by 1, next part of the sequence of 6
  sequence_step %= 6;                 //If step > 5 (equal to 6) then step = 0 and start over
}







//Switch to next step functions
void set_next_step(){        
  switch(sequence_step){
    case 0:
      AH_BL();
      BEMF_C_RISING();
      break;
    case 1:
      AH_CL();
      BEMF_B_FALLING();
      break;
    case 2:
      BH_CL();
      BEMF_A_RISING();
      break;
    case 3:
      BH_AL();
      BEMF_C_FALLING();
      break;
    case 4:
      CH_AL();
      BEMF_B_RISING();
      break;
    case 5:
      CH_BL();
      BEMF_A_FALLING();
      break;
  }
}//end of set_next_step







//main loop
void loop() {
  /*if PWM input is higher than PWM_IN_MIN + 115 we start the motor*/
  if(PWM_INPUT > (PWM_IN_MIN + 115) && ESC_MODE_ON)
  {
    MOTOR_SPINNING = true;  
    full_stop = false;  
    motor_off_counter = 0;    
  }
  //////////////////////////Motor is rotating////////////////////////
  if(MOTOR_SPINNING)
  {  
    SET_PWM(PWM_value);     // Setup starting PWM with duty cycle = PWM_START_DUTY
    i = 2000;
    // Motor start
    while(i > 500) {
      delayMicroseconds(i);
      set_next_step();
      sequence_step++;
      sequence_step %= 6;
      i = i - 10;
    }
    motor_speed = PWM_value;   
    set_next_step();
    ACSR |= 0x08;                    // Enable analog comparator interrupt  
    while(MOTOR_SPINNING) 
    {
      PWM_INPUT = constrain(PWM_INPUT,PWM_IN_MIN,PWM_IN_MAX);
      motor_speed = map(PWM_INPUT,PWM_IN_MIN,PWM_IN_MAX,PWM_min_value,PWM_max_value);
      SET_PWM(motor_speed);
      if(PWM_INPUT < (PWM_IN_MIN + 30))
      {
        if(motor_off_counter > 10000)
        {          
          MOTOR_SPINNING = false;
          motor_off_counter = 0;
          PORTD = B00000000;      //Set D0-D7 to LOW        
          TCCR1A =  0;            //OC1A - D9 compare match noninverting mode, downcounting ,PWM 8-bit 
          TCCR2A =  0;            //OC1A - D9 compare match noninverting mode, downcounting ,PWM 8-bit 
          previousMillis = millis();
        }
        motor_off_counter = motor_off_counter + 1;       
      }      
    }
  }//end of if MOTOR_SPINNING
  

  //////////////////////////Motor STOP////////////////////////
  if(!MOTOR_SPINNING)
  { 
    unsigned long currentMillis = millis();
    if(currentMillis - previousMillis >= 4000 && !full_stop)
    { 
      previousMillis += 4000;  
      full_stop = true;
    }
    if(full_stop)
    {
      if(currentMillis - previousMillis >= 2000)
      {  
        previousMillis += 2000;        
        ACSR   = 0x10;            // Disable and clear (flag bit) analog comparator interrupt
        TCCR2A =  0;
        TCCR1A =  0;
        PORTD  = 0x00;            //pins 0 to 7 set to LOW //stop everything    
        PORTB  &= 0x31;           //B00110001    D9, D10 and D11 to LOW  
        OCR1A = beeping_PWM_VALUE; 
        beep_1KHZ(100);     //make a 100 ms beep               
      } 
    }
    else
    {
      ACSR   = 0x10;            // Disable and clear (flag bit) analog comparator interrupt
      TCCR2A =  0;
      TCCR1A =  0;
      PORTD  = B00000000;            //pins 0 to 7 set to LOW //stop everything    
      PORTB  = B00000000;           //B00110001    D9, D10 and D11 to LOW           
    }     
  }//end of if !MOTOR_SPINNING
}//end of void loop












/*On each step we know that the next 0 cross will be rising or falling and if it will be
on coil A, B or C. With these funcstions we select that according to the step of the sequence*/
void BEMF_A_RISING(){  
  ADCSRA = (0 << ADEN);     // Disable the ADC module
  ADCSRB = (1 << ACME);     // MUX select for negative input of comparator
  ADMUX = 2;                // Select A2 as comparator negative input
  ACSR |= 0x03;             // Set interrupt on rising edge*/
}
void BEMF_A_FALLING(){
  ADCSRA = (0 << ADEN);     // Disable the ADC module
  ADCSRB = (1 << ACME);     // MUX select for negative input of comparator
  ADMUX = 2;                // Select A2 as comparator negative input
  ACSR &= ~0x01;            // Set interrupt on falling edge*/
}
void BEMF_B_RISING(){
  ADCSRA = (0 << ADEN);     // Disable the ADC module
  ADCSRB = (1 << ACME);     // MUX select for negative input of comparator
  ADMUX = 1;                // Select A1 as comparator negative input
  ACSR |= 0x03;             // Set interrupt on rising edge
}
void BEMF_B_FALLING(){
  ADCSRA = (0 << ADEN);     // Disable the ADC module
  ADCSRB = (1 << ACME);     // MUX select for negative input of comparator
  ADMUX = 1;                // Select A1 as comparator negative input
  ACSR &= ~0x01;            // Set interrupt on falling edge*/
}
void BEMF_C_RISING(){
  ADCSRA = (0 << ADEN);     // Disable the ADC module
  ADCSRB = (1 << ACME);     // MUX select for negative input of comparator
  ADMUX = 0;                // Select A0 as comparator negative input
  ACSR |= 0x03;             // Set interrupt on rising edge
}
void BEMF_C_FALLING(){
  ADCSRA = (0 << ADEN);     // Disable the ADC module
  ADCSRB = (1 << ACME);     // MUX select for negative input of comparator
  ADMUX = 0;                // Select A0 as comparator negative input
  ACSR &= ~0x01;            // Set interrupt on falling edge*/
}










/*On each step we change the digital pins to be HIGH or LOW or to be PWM or no-PWM 
depending on which step of the sequence we are*/
//D9 PWM and D3 HIGH.  
void AH_BL(){
  PORTD = B00001000;      //Set D3 (BL) to HIGH and the rest to LOW
  TCCR2A =  0;            //OC2A - D11 normal port. 
  TCCR1A =  0x81;         //OC1A - D9 (AH) compare match noninverting mode, downcounting ,PWM 8-bit
}
//D9 PWM and D2 HIGH
void AH_CL(){
  PORTD = B00000100;      //Set D2 (CL) to HIGH and the rest to LOW
  TCCR2A =  0;            //OC2A - D11 normal port. 
  TCCR1A =  0x81;         //OC1A - D9 (AH) compare match noninverting mode, downcounting ,PWM 8-bit  
}
//D10 PWM and D2 HIGH
void BH_CL(){
  PORTD = B00000100;      //Set D2 (CL) to HIGH and the rest to LOW
  TCCR2A =  0;            //OC2A - D11 normal port. 
  TCCR1A =  0x21;         //OC1B - D10 (BH) compare match noninverting mode, downcounting ,PWM 8-bit 
}
//D10 PWM and D4 HIGH
void BH_AL(){  
  PORTD = B00010000;      //Set D4 (AL) to HIGH and the rest to LOW
  TCCR2A =  0;            //OC2A - D11 normal port. 
  TCCR1A =  0x21;         //OC1B - D10 (BH) compare match noninverting mode, downcounting ,PWM 8-bit 
}
//D11 PWM and D4 HIGH
void CH_AL(){ 
  PORTD = B00010000;      //Set D4 (AL) to HIGH and the rest to LOW
  TCCR1A =  0;            // OC1A and OC1B normal port
  TCCR2A =  0x81;         // OC2A - D11 (CH) compare match noninverting mode, downcounting ,PWM 8-bit  
}
//D11 PWM and D3 HIGH
void CH_BL(){  
  PORTD = B00001000;      //Set D3 (BL) to HIGH and the rest to LOW
  TCCR1A =  0;            // OC1A and OC1B normal port
  TCCR2A =  0x81;         // OC2A - D11 (CH) compare match noninverting mode, downcounting ,PWM 8-bit
}








/*This function will only change the PWM values according to the received width_value
that is given by the PWM read on pin D8*/
void SET_PWM(byte width_value){
  //We keep the range of PWM between min and max (8 bit value)
  if(width_value < PWM_min_value)    width_value  = PWM_min_value;
  if(width_value > PWM_max_value)    width_value  = PWM_max_value;
  OCR1A  = width_value;                   // Set pin 9  PWM duty cycle
  OCR1B  = width_value;                   // Set pin 10 PWM duty cycle
  OCR2A  = width_value;                   // Set pin 11 PWM duty cycle
}






/*This is the interruption routine on pin change
in this case for digital pin D8 which is the PWM input*/
ISR(PCINT0_vect){
  //First we take the current count value in micro seconds using the micros() function
  current_count = micros();
  ///////////////////////////////////////Channel 1
  if(PINB & B00000001){                              //We make an AND with the pin state register, We verify if pin 8 is HIGH???
    if(last_PWM_state == 0){                         //If the last state was 0, then we have a state change...
      last_PWM_state = 1;                            //Store the current state into the last state for the next loop
      counter_1 = current_count;                     //Set counter_1 to current value.
    }
  }
  else if(last_PWM_state == 1){                      //If pin 8 is LOW and the last state was HIGH then we have a state change      
    last_PWM_state = 0;                              //Store the current state into the last state for the next loop
    PWM_INPUT = current_count - counter_1;           //We make the time difference. PWM_INPUT is current_time - counter_1 in micro-seconds.
  }
}

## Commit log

2026-02-05 Initial ESC firmware upload
    Initial upload of BLDC ESC firmware source files written in C, including PWM input handling, EEPROM configuration, and commutation logic.
2026-02-05 Add ESC V3 hardware files
    Initial upload of ESC V3 hardware documentation including PCB files, Gerbers, schematic, BOM, and reference images.
    [ESCV3.PcbDoc, ESCV3.PcbLib, ESCV3.PrjPcb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]
